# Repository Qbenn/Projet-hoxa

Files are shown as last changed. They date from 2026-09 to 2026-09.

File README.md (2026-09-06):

# Napęd wentylatora — projekt PKM

Projekt konstrukcyjny napędu wentylatora wykonany w ramach przedmiotu
Podstawy Konstrukcji Maszyn (PKM).

## Zawartość

| Plik | Opis |
|---|---|
| `design-calculations.pdf` | Dokumentacja obliczeniowa projektu |
| `assembly-drawing.pdf` | Rysunek złożeniowy |
| `driven-wheel-drawing.pdf` | Koło bierne (rysunek wykonawczy) |
| `shaft-drawing.pdf` | Wał (rysunek wykonawczy) |
| `fan-assembly.stl` | Model 3D złożenia (STL) |

## Technologie

- Modelowanie 3D / CAD
- Rysunek techniczny
- Obliczenia wytrzymałościowe (wał, łożyska, połączenia)

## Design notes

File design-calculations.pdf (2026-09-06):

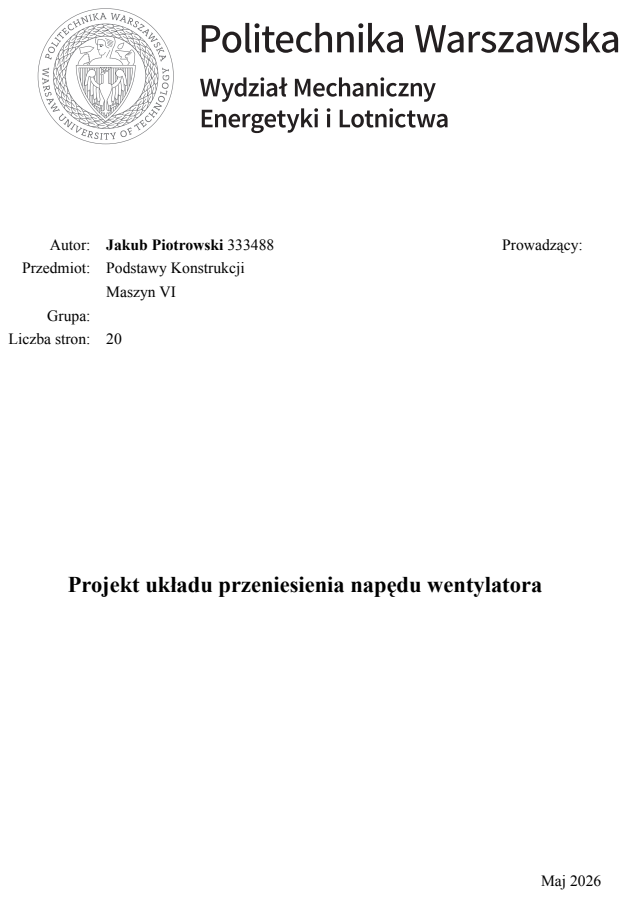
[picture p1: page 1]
Maszyn VI; Grupa:; Liczba stron: 20; Prowadzący:; Maj 2026

Autor: Jakub Piotrowski 333488
Przedmiot: Podstawy Konstrukcji

Projekt układu przeniesienia napędu wentylatora

## Spis treści

1 Wstęp | 1
1.1 Rysunek poglądowy i wymiary gabarytowe | | 1
1.2 Dane wyjściowe projektu | | 2
1.3 Zastosowane materiały | | 3
2 Dobór silnika elektrycznego | 4
3 Obliczenia przekładni pasowej | 4
4 Obliczenia wytrzymałościowe wału napędowego | 7
4.1 Rozplanowanie umieszczenia elementów na wale | | 7
4.2 Statyka wału | | 8
4.3 Rozkład obciążeń wewnętrznych | | 10
4.4 Analiza wytrzymałości doraźnej wału | | 11
4.5 Analiza ugięcia i obrotów krytycznych wału | | 12
4.6 Analiza wytrzymałości zmęczeniowej wału | | 12
4.7 Dobór wpustów | | 14
5 Dobór łożysk | 14
5.1 Wybrany model łożyska | | 14
5.2 Obliczenia sprawdzające nośność łożyska | | 15
5.3 Oprawy łożyskowe | | 16
6 Statyka ramy | 16
6.1 Konstrukcja ramy | | 16
6.2 Wstępna analiza MES ramy | | 17
7 System naciągu pasa | 18

## Spis rysunków

1 | Rysunek poglądowy układu napędowego wentylatora | | 1
2 | Widok ogólny układu napędowego | | 2
3 | Wymiary całego systemu | | 2
4 | Rozplanowanie umieszczenia elementów na wale | | 8
5 | Wał napędowy przed i po uwolnieniu od więzów | | 8
6 | Rozkład sił tnących i siły normalnej na wale | | 10
7 | Rozkład momentów gnących i skręcającego na wale | | 10
8 | Rozkład momentu zastępczego i wypadkowego momentu gnącego | | 11

9 | Porównanie średnicy teoretycznej i rzeczywistej wału napędowego | | 11
10 | Miejsca analizowane pod kątem wytrzymałości zmęczeniowej | | 12
11 | Izometryczny widok konstrukcji ramy | | 17
12 | Ugięcie ramy w kierunku Y (z odwzorowaniem kształtu ugięcia) | | 18
13 | System naciągu pasa SIT S.p.A. TC112 | | 19

## 1 Wstęp

Celem projektu jest zaprojektowanie układu przenoszenia napędu służącego do zasilania wentylatora. Urządzenie składa się z silnika elektrycznego, przekładni pasowej, systemu naciągu pasa, obudowanych łożysk i ramy.

### 1.1 Rysunek poglądowy i wymiary gabarytowe

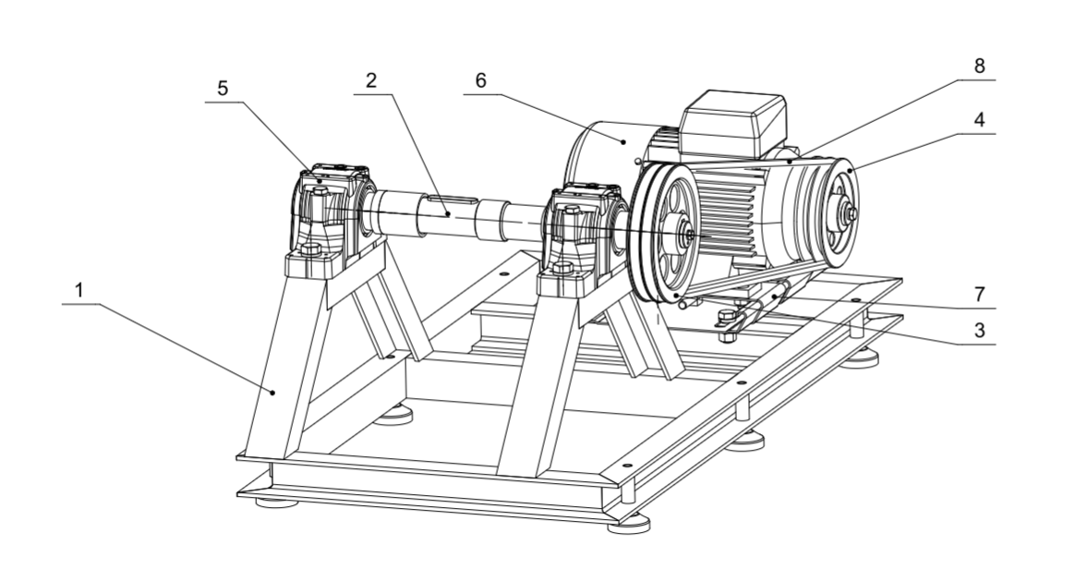
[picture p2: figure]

Rysunek 1: Rysunek poglądowy układu napędowego wentylatora

Głównymi elementami układu są:

1. rama,
2. wał napędowy,
3. koło bierne,
4. koło czynne,
5. łożyska w oprawie,
6. silnik elektryczny,
7. układ naciągu pasa,
8. pas klinowy.

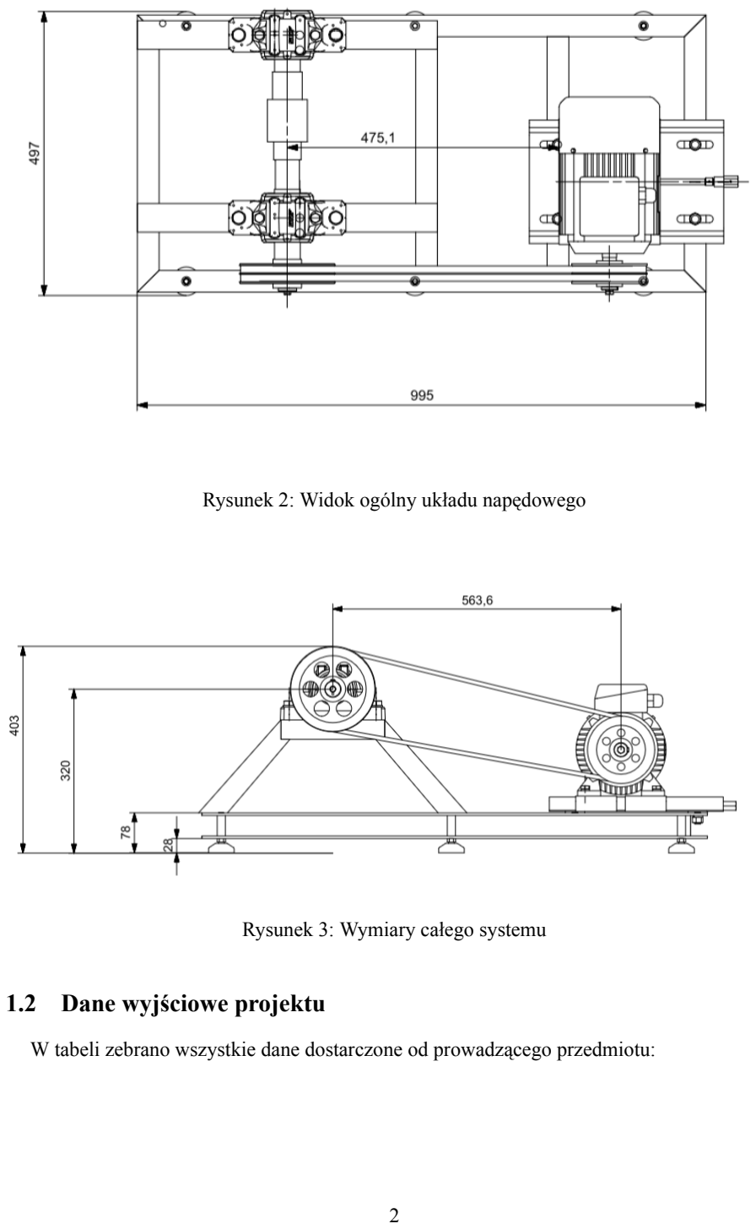
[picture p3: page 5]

Rysunek 2: Widok ogólny układu napędowego

Rysunek 3: Wymiary całego systemu

### 1.2 Dane wyjściowe projektu

W tabeli zebrano wszystkie dane dostarczone od prowadzącego przedmiotu:

OZNACZENIE WARTOŚĆ JEDNOSTKA
MOC UŻYTKOWA | P | 1,15 | kW
PRĘDKOŚĆ OBROTOWA | n | 1100 | obr/min
TRWAŁOŚĆ ŁOŻYSK | L10h | 125000 | h
SIŁA WZDŁUŻNA | FW | 310 | N
CIĘŻAR WENTYLATORA | FQ | 135 | N
WYMIAR GEOMETRYCZNY 1 | a | 515 | mm
WYMIAR GEOMETRYCZNY 2 | b | 322 | mm
WYMIAR GEOMETRYCZNY 3 | c | 320 | mm

Tabela 1: Parametry wejściowe

### 1.3 Zastosowane materiały

Zdecydowano, aby elementy urządzenia nieunormowane wykonać z następujących materiałów:

MATERIAŁ | PARAMETR | WARTOŚĆ | NORMA | ZASTOSOWANIE
S235JR | Re Rm | 235 MPa 410 MPa | PN-EN 10025:2002 | rama, tulejki gwintowane, płytki wyrównujące
C35 | Re Rm Zgo | 300 MPa 520 MPa 238,5 MPa | PN-EN 10083-2 | wał napędowy, tulejki dystan-sujące
C45 | Re Rm | 305 MPa 580 MPa | PN-EN 10083-2 | wpusty
PN-GJL 200 | Rm HB | 155 MPa 150 | PN-EN 1561:2000 | koła przekładni pasowej

Tabela 2: Właściwości materiałów użytych w projekcie

Stal S235JR wybrano do wykonania ramy ze względu na jej łatwą obróbkę i dobrą spawalność. Stale C35 i C45 wybrano ze względu na ich dobre właściwości wytrzymałościowe, możliwość umacniania cieplnego oraz łatwą obróbkę skrawaniem. Zdecydowano, aby koła przekładni wykonać w technologii odlewania.

## 2 Dobór silnika elektrycznego

Moc niezbędna:

Prozp =

Puzyt
ηo

=

P
ηpp ·ηb ·ηb

Na podstawie danych przedstawionych w [1] przyjęto następujące wartości współczynników:

WIELKOŚĆ | OZNACZENIE WARTOŚĆ LICZBOWA
SPRAWNOŚĆ PRZEKŁADNI PASOWEJ | ηpp | 0,93
SPRAWNOŚĆ PARY ŁOŻYSK KULKOWYCH | ηb | 0,99

Tabela 3: Wartości sprawności w układzie przeniesienia napędu

Stąd minimalna moc silnika elektrycznego wynosi:

Prozp =

Puzyt
ηo

=

1,15
0,93 · 0,99 · 0,99

≈ 1,26 kW

Na podstawie obliczeń dobrano trójfazowy silnik indukcyjny firmy Celma Indukta, model SH90L-4, o mocy 1,5 kW i prędkości 1410 obr/min. Jego parametry przedstawiono w tabeli:

OZNACZENIE WARTOŚĆ JEDNOSTKA

MOC ZNAMIONOWA | Ps | 1,5 | kW
PRĘDKOŚĆ OBROTOWA | ns | 1410 | obr/min

Tabela 4: Wybrane parametry silnika

Teoretyczne przełożenie układu przenoszenia napędu:

ut =

ns
n
| =
| 1410
| 1100

≈ 1,28

Moment na wale silnika wynosi:

T1 =

Prozp
ns
- 9550 =
| 1,26
| 1410 | · 9550 = 8,534 Nm

## 3 Obliczenia przekładni pasowej

Pierwszym krokiem jest wybranie typu paska. W tym celu należy obliczyć moment obliczeniowy na wale silnika:
| T10 = kt

·T1

Współczynnik kt uwzględnia trwałość pasa klinowego. Dla lekkich warunków pracy, silnika trójfazowego i pracy do 16 godzin na dobę przyjęto kt = 1,2:

T1o = 1,2 · 8,534 = 10,24 Nm < 30 Nm

Przyjęty typ paska to HA. Średnicę skuteczną koła czynnego wybrano równą rozmiarowi

odpowiadającemu jak najlepszej wartości przenoszenia napędu: D1s = 125 mm. Prędkość pasa wynosi:
ϑ =

D1s

- n1 · π
60 · 10³

= 9,223

m
s

< 25 m
s
Zatem warunek prędkości pasa jest spełniony. Średnicę skuteczną koła biernego przyjęto jako pierwszy rozmiar mniejszy lub równy średnicy teoretycznej. Średnicę teoretyczną wyznaczono

z:

D2t = D1s

·it = 125 · 1,28 ≈ 160 mm

D2s = 160 mm

Rzeczywiste przełożenie przekładni obliczono z zależności:

i =

D2s

D1s

·(1−ε)

Współczynnik ε opisuje poślizg sprężysty pasa. Jego wartość przyjęto równą ε = 0,015.

Podstawiając:

i =

160
125 ·(1−0,015)

≈ 1,299

# |it −i|

i

=

|1,28−1,299|
1,28

≈ 1,48% < 4%

Zatem warunek jest spełniony. Odległość osi dobrano z warunku postawionego w założeniach projektowych: az = 570 mm. Jest ona większa niż odległość zalecana, wyznaczona z zależności, gdzie ka to współczynnik odległości osi:

at = ka ·D2s = 1,2 · 160 = 192 mm

Obliczeniową długość pasa obliczono ze wzoru:

Lp = 2az +0,5π ·(D2s +D1s) +0,25 ·

(D2s −D1s)

2

az

= 1588,24 mm

Rzeczywista wartość na podstawie tabeli w literaturze:

Lp = 1600 mm

Ostateczna odległość między osiami silnika i wentylatora:

a = az +0,5 ·(Lp −L

′
p

) = 575,89 mm

Liczba obiegów pasa i kąt opasania koła czynnego wynoszą:

ν =

10³

·ϑ

Lp

=

1000 · 9,22
1600

= 5,77 < 15 = νdop

α = 180◦ −57◦
·

D2s −D1s
a

= 180◦ −57◦
·

160−125
570 = 176◦ > 110◦

Oba warunki z literatury są spełnione. Moc przenoszona przez jeden pas:

Pobl = P0 · kl

- kα

gdzie P0 = 2 kW to nominalna moc przenoszona przez jeden pas (odczytana z tablic dla D1s = 125 mm, ϑ ≈ 10 m/s), kl = 0,99 to współczynnik uwzględniający długość pasa, zaś kα = 0,99

to współczynnik uwzględniający kąt opasania koła czynnego. Wartości odczytano z tablic w literaturze:
Pobl = 2 · 0,99 · 0,99 = 1,96 kW

Obliczeniowa liczba pasów wynosi:

zobl =

P1 · kT

Pobl

=

1,8 · 1,2
1,96

≈ 1,10

Przyjęto liczbę pasów z = 2. Obciążenia występujące w przekładni obliczono z zależności:

Ft =

2 · 10³
·T1o

D1s

=

2000 · 10,24
125

≈ 163,84 N

F0 =

Ft
2 ·Ψ

=

163,84
2 · 0,55

≈ 148,94 N

F = 2 ·F0 ·sin(α

2

)

= 2 · 148,94 ·sin(
176◦

2

)
= 298,1 N

gdzie Ψ = 0,55 to współczynnik napędu. Dla przekładni z okresową kontrolą napięcia pasa

maksymalna siła obciążająca wał wynosi:

Fmax = 1,3 ·F = 1,3 · 298,1 = 387,65 N

W tabeli zestawiono wszystkie obliczone lub przyjęte wielkości użyte w tym rozdziale.

| OZNACZENIE | WARTOŚĆ | JEDNOSTKA
WSPÓŁCZYNNIK TRWAŁOŚCI PASA | kT | 1,2 | -
MOMENT OBLICZENIOWY | T1o | 10,24 | Nm
ŚREDNICA KOŁA CZYNNEGO | D1s | 125 | mm
PRĘDKOŚĆ PASA | ϑ | 9,223 | m/s
MAKSYMALNA ŚREDNICA KOŁA BIERNEGO | D2max | 160 | mm
PRZYJĘTA ŚREDNICA KOŁA BIERNEGO | D2 | 160 | mm
WSPÓŁCZYNNIK POŚLIZGU | ε | 0,015 | -
RZECZYWISTE PRZEŁOŻENIE | urz | 1,299 | -
WARUNEK PRZEŁOŻEŃ | - | 1,48% | -
WSPÓŁCZYNNIK ODLEGŁOŚCI MIĘDZY KOŁAMI | ka | 1,2 | -
ZALECANA ODLEGŁOŚĆ OSI | at | 192 | mm
OBLICZENIOWA DŁUGOŚĆ PASA | L

′
| p | 1588,24 | mm
PRZYJĘTA ODLEGŁOŚĆ MIĘDZY OSIAMI KÓŁ | az | 570 | mm
RZECZYWISTA DŁUGOŚĆ PASA | Lp | 1600 | mm
OSTATECZNA ODLEGŁOŚĆ MIĘDZY OSIAMI KÓŁ | a | 575,89 | mm
LICZBA OBIEGÓW PASA | ν | 5,77 | 1/s
KĄT OPASANIA KOŁA CZYNNEGO | α | 176 | ◦
WSPÓŁCZYNNIK DŁUGOŚCI PASA | kl | 0,99 | -
WSPÓŁCZYNNIK KĄTA OPASANIA | kα | 0,99 | -
MOC NOMINALNA PRZENOSZONA PRZEZ PAS | P0 | 2 | kW
MOC PRZENOSZONA PRZEZ JEDEN PAS | Pobl | 1,96 | kW
OBLICZENIOWA LICZBA PASÓW | zobl | 1,1 | -
WYBRANA LICZBA PASÓW | z | 2 | -
SIŁA OBWODOWA | Ft | 163,84 | N
WSPÓŁCZYNNIK NAPĘDU | Ψ | 0,55 | -
NAPIĘCIE WSTĘPNE PASA | F0 | 148,94 | N
SIŁA OBCIĄŻAJĄCA WAŁ | F | 298,1 | N
SIŁA MAKSYMALNA DLA PRZEKŁADNI Z KONTROLĄ PASA | Fmax | 387,65 | N

Tabela 5: Zestawienie wielkości użytych do obliczeń przekładni

## 4 Obliczenia wytrzymałościowe wału napędowego

### 4.1 Rozplanowanie umieszczenia elementów na wale

Przed rozpoczęciem obliczeń należy rozplanować rozkład elementów układu na wale napędowym. Uproszczony rysunek przedstawiający rozmieszczenie najważniejszych elementów zamieszczono poniżej.

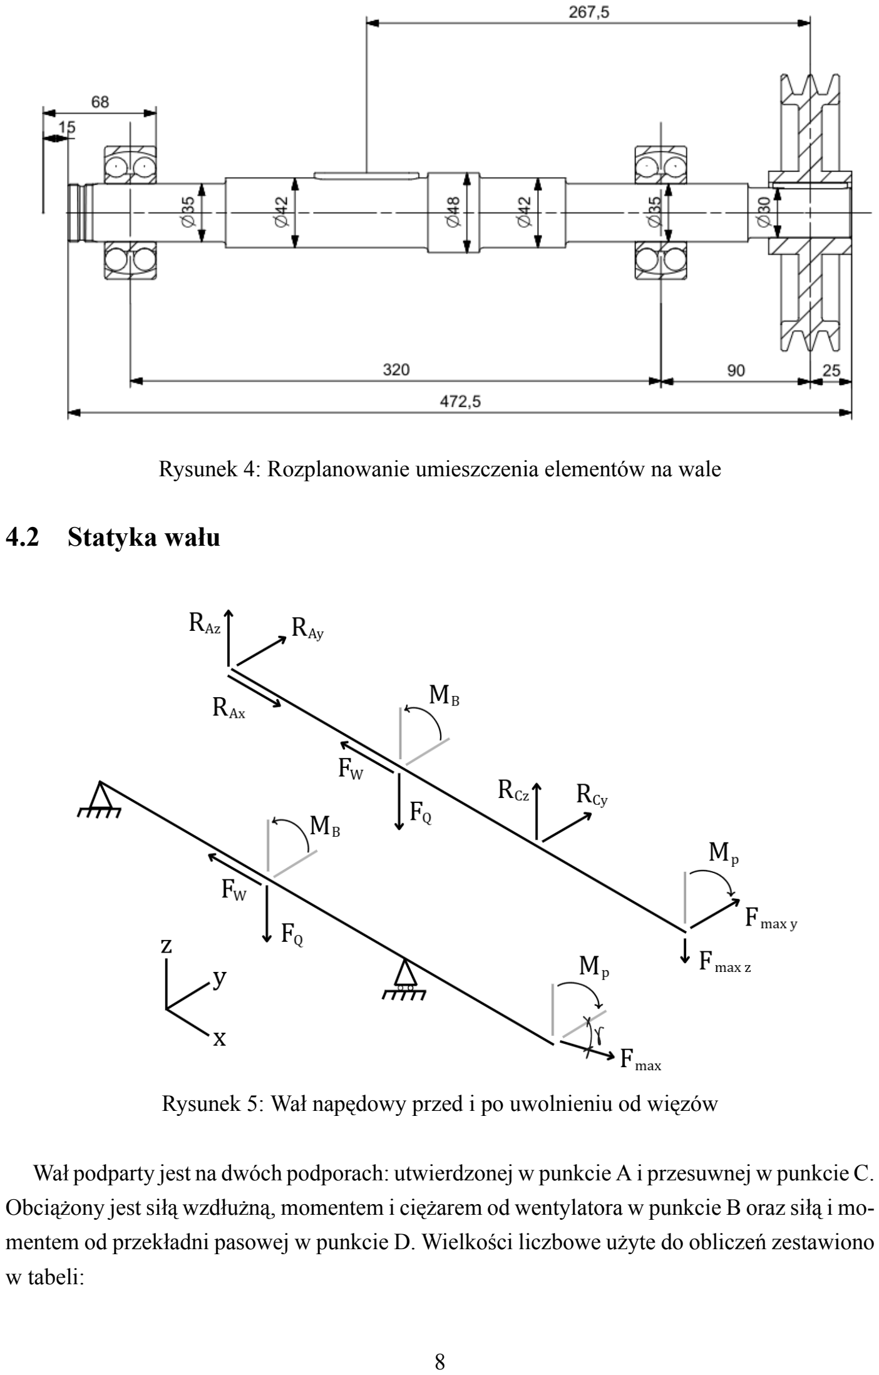
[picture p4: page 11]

Rysunek 4: Rozplanowanie umieszczenia elementów na wale

### 4.2 Statyka wału

Rysunek 5: Wał napędowy przed i po uwolnieniu od więzów

Wał podparty jest na dwóch podporach: utwierdzonej w punkcie A i przesuwnej w punkcie C. Obciążony jest siłą wzdłużną, momentem i ciężarem od wentylatora w punkcie B oraz siłą i momentem od przekładni pasowej w punkcie D. Wielkości liczbowe użyte do obliczeń zestawiono w tabeli:

| OZNACZENIE | WARTOŚĆ | JEDNOSTKA
SIŁA WZDŁUŻNA | FW | 310 | N
CIĘŻAR WENTYLATORA | FQ | 135 | N
MAKSYMALNA SIŁA OBCIĄŻAJĄCA WAŁ OD PRZEKŁADNI | Fmax | 387,65 | N
KĄT POMIĘDZY PŁASZCZYZNĄ XY I SIŁĄ Fmax | γ | 0,296 | rad
SKŁADOWA NA KIERUNEK y SIŁY OBCIĄŻAJĄCEJ WAŁ | Fmax,y | 370,7 | N
SKŁADOWA NA KIERUNEK z SIŁY OBCIĄŻAJĄCEJ WAŁ | Fmax,z | 113,3 | N
MOMENT OD PRZEKŁADNI | Mp | 9,98 | Nm
ODLEGŁOŚĆ MIĘDZY ŁOŻYSKIEM A A PUNKTEM PRZYŁOŻENIA SIŁ OD WENTYLATORA | lAB | 142.5 | mm
ODLEGŁOŚĆ MIĘDZY ŁOŻYSKIEM A A ŁOŻYSKIEM C | lAC | 320 | mm
ODLEGŁOŚĆ MIĘDZY ŁOŻYSKIEM A A PUNKTEM PRZYŁOŻENIA SIŁ OD KOŁA PASOWEGO | lAD | 410 | mm

Tabela 6: Wartości obciążeń i wymiarów użyte do obliczeń statyki

Poniżej przedstawiono równania równowagi statycznej dla opisanego układu:

∑Fx = RAx −FW = 0

∑Fy = RAy +RCy +Fmax,y = 0

∑Fz = RAz +RCz −Fmax,z −FQ = 0

∑MDx = MB − Mp = 0

∑MDy = RAz ·lAD −FQ ·lBD +RCz ·lCD = 0

∑MDz = −RAy ·lAD −RCy ·lCD = 0

Po rozwiązaniu równań otrzymano:

Wielkość Wartość Jednostka
RAx | 310 | N
RAy | 104,26 | N
RAz | 43 | N
RCy | −474,9 | N
RCz | 205,3 | N
FQ | 135 | N
MB | 9,98 | Nm

Tabela 7: Reakcje wyznaczone z równań równowagi statycznej

Na potrzeby rozwiązania układu założono, że reakcja wzdłużna odbierana jest przez łożysko A.

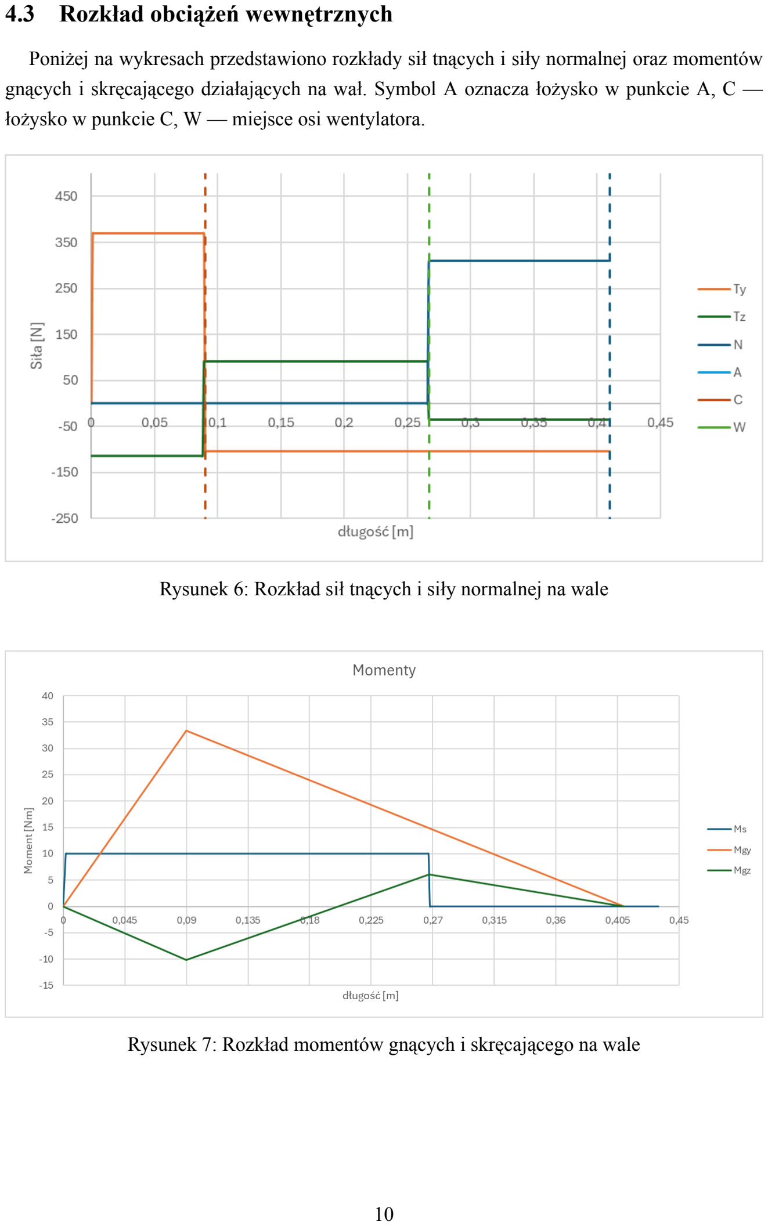
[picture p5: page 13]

### 4.3 Rozkład obciążeń wewnętrznych

Poniżej na wykresach przedstawiono rozkłady sił tnących i siły normalnej oraz momentów gnących i skręcającego działających na wał. Symbol A oznacza łożysko w punkcie A, C — łożysko w punkcie C, W — miejsce osi wentylatora.

Rysunek 6: Rozkład sił tnących i siły normalnej na wale

Rysunek 7: Rozkład momentów gnących i skręcającego na wale

### 4.4 Analiza wytrzymałości doraźnej wału

Aby wyznaczyć minimalny promień z warunku wytrzymałości doraźnej, posłużono się wzorem z [1]:

r0 =

1
2

·
3

√
Mzast · 1000 · n
Zgo · 0,1

gdzie n = 1,5 to przyjęty współczynnik bezpieczeństwa, Zgo to granica wytrzymałości materiału na zginanie obustronne, która dla stali C35 wynosi 238,5 MPa. Moment zastępczy wyznaczono ze wzoru:

Mzast =

√
M²

gz + M²

gy + (α · Ms)
2

Wartość współczynnika α przyjęto zakładając, że kierunek obrotu wału się nie zmienia:
α ≈

√
3
4

. Poniżej na wykresach przedstawiono rozkład momentu zastępczego, promienia minimalnego i przyjętych promieni wału napędowego. Przyjęte promienie zostały dobrane z wystarczającym zapasem, zapewniającym odporność wału na zniszczenie doraźne.

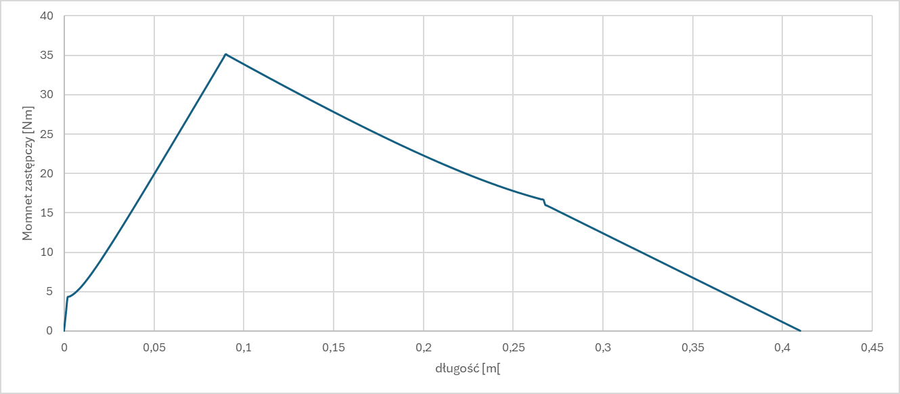
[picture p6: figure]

Rysunek 8: Rozkład momentu zastępczego i wypadkowego momentu gnącego

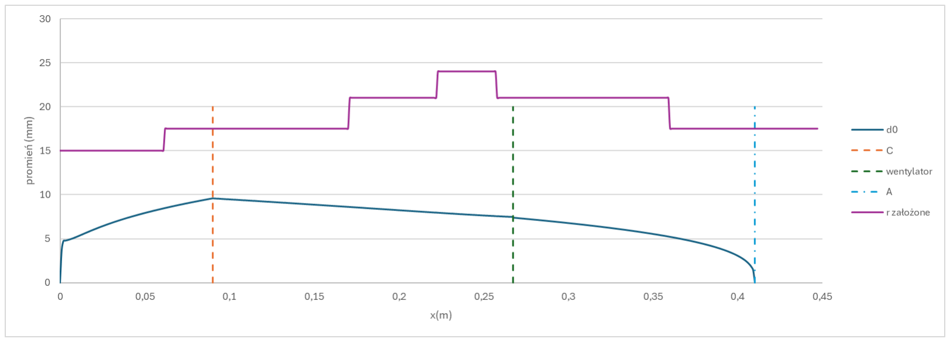
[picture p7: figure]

Rysunek 9: Porównanie średnicy teoretycznej i rzeczywistej wału napędowego

Rzeczywiste średnice są zdecydowanie większe niż wyniki teoretyczne. Wynika to z faktu, że najbardziej krytycznym warunkiem wytrzymałościowym jest ugięcie wału oraz wymagana trwałość godzinowa łożysk, a nie wytrzymałość doraźna.

### 4.5 Analiza ugięcia i obrotów krytycznych wału

Do wyznaczenia ugięcia wału przyjęto model uproszczony ze stałą średnicą równą średnicy minimalnej. Ugięcie wału obliczono ze wzoru:

fc =

P· a

2

3EJy

(l +a)

gdzie P = 387,67 N to siła od przekładni, a = 97,5 mm to odległość przyłożenia siły od łożyska C, l = 320 mm to odległość między łożyskami, E = 2,1·10⁵ MPa to moduł Younga dla stali, a Jy dla najmniejszej średnicy wału (d = 35 mm) wynosi Jy = 73661,4 mm⁴
. Podstawiając:

fc =

387,65 · 97,5

2
·(320+97,5)
3 · 2,1 · 10⁵
- 73661,4

= 0,0458 mm < l · 10−4 = 0,064 mm

Prędkość krytyczna dla wyznaczonego ugięcia:

nkr =

√ g

fc

=

√
9,81
0,0458 · 10−3

≈ 462,5

rad
s

0,85 · nkr = 0,85 · 462,5 ·

60
2π

= 3754 obr
min > 1100

obr
min
Warunki ugięcia i prędkości krytycznej są spełnione.

### 4.6 Analiza wytrzymałości zmęczeniowej wału

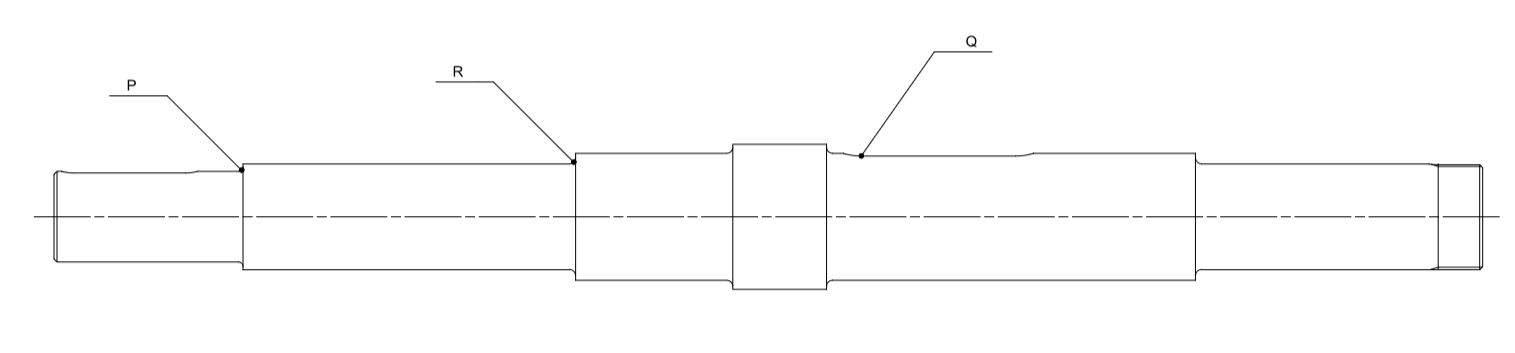
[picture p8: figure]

Rysunek 10: Miejsca analizowane pod kątem wytrzymałości zmęczeniowej

Do zbadania wytrzymałości zmęczeniowej wału wybrano trzy przekroje, w których przewiduje się największe zagrożenie uszkodzeniem zmęczeniowym: odsadzenie w punkcie P, odsadzenie w punkcie R oraz rowek wpustowy pod piastę wentylatora w punkcie Q.

Rzeczywisty współczynnik bezpieczeństwa dla obciążeń złożonych obliczono z zależności:

δ = √

## δσ · δτ

δ
2

σ +δ
2
τ

gdzie δσ to współczynnik bezpieczeństwa na zginanie, a δτ to współczynnik bezpieczeństwa

na skręcanie, obliczone ze wzorów:
δσ =

Zgo · ε

## σa · β

δτ =

Zso · ε

## τa · β +ψ · τm

Symbole: Zgo, Zso — granice wytrzymałości zmęczeniowej materiału; ε — współczynnik wielkości; ψ — współczynnik podatności na asymetrię cyklu; β — wypadkowy współczynnik działania karbu; σa, τa — amplitudy naprężeń normalnych i stycznych. Dla stałego kierunku obrotów wału przyjęto τa = τm. Wypadkowy współczynnik działania karbu obliczono ze wzoru

podanego w [4]:

## β = βk +βp −1 = 1+ (αk −1)ηk +βp −1

Dla obliczenia współczynnika bezpieczeństwa w rowku wpustowym (punkt Q) użyto wartości współczynników działania karbu podanych w [1]. Wyznaczone wartości oraz końcowe wyniki zestawiono w tabeli:

Parametr | P | Q | R | Jednostka
d | 30 | 42 | 35 | mm
Wg | 2651 | 7273,57 | 4209,24 | mm³
Mg | 14,94 | 20,7 | 28,178 | Nm
Ms | 10 | 10 | 10 | Nm
σa | 5,639 | 2,846 | 6,694 | MPa
τa | 1,89 | 0,687 | 1,19 | MPa
Zgo | 238,5 | 238,5 | 238,5 | MPa
Zso | 141 | 141 | 141 | MPa
ε | 0,87 | 0,83 | 0,85 | -
βkσ | 1,95 | 1,75 | 1,85 | -
βkτ | 1,50 | 1,50 | 1,40 | -
βpσ | 1,08 | 1,08 | 1,00 | -
βpτ | 1,08 | 1,08 | 1,00 | -
βσ | 2,03 | 1,83 | 1,85 | -
βτ | 1,58 | 1,58 | 1,40 | -
ψτ | 0,05 | 0,05 | 0,05 | -
δσ | 18,13 | 38,00 | 16,37 | -
δτ | 39,82 | 107,5 | 68,29 | -
δ | 16,50 | 35,83 | 15,92 | -

Tabela 8: Wyniki obliczeń współczynników bezpieczeństwa zmęczeniowego (wg Kurmaz, Tabl. 8.6.1 i 8.6.2, Rys. 8.6.5)

W wszystkich analizowanych przekrojach współczynniki bezpieczeństwa zmęczeniowego są co najmniej ośmiokrotnie wyższe od przyjętego współczynnika bezpieczeństwa. Warunek wytrzymałości zmęczeniowej jest spełniony.

### 4.7 Dobór wpustów

Zdecydowano, aby wpust pod piastą wentylatora mocowany był na wcisk, a wpust pod piastą koła biernego połączeniem gwintowym. Dopuszczalne naciski powierzchniowe wynoszą odpowiednio: pdop = 30 MPa dla wpustu pod piastą wentylatora i pdop = 60 MPa dla wpustu pod piastą koła. Długość wpustu wyznaczono z warunku nacisków dopuszczalnych:

l ≥

2ktM · 1000
pdop · d ·(h−t1)

Dla wpustu pod piastą koła biernego: h = 7 mm, d = 30 mm, t1 = 4 mm, b = 8 mm:

l ≥

2 · 1,2 · 9,98 · 1000
60 · 30 ·(7−4)

≥ 4,76 mm

Dla wpustu pod piastą wentylatora: h = 8 mm, d = 42 mm, t1 = 5 mm, b = 12 mm:

l ≥

2 · 1,2 · 9,98 · 1000
30 · 42 ·(8−5)

≥ 6,34 mm

Przyjęto wpusty o jednakowej długości, wynoszącej 45 mm (minimalna dla wpustu o szerokości 8 mm). Dobrano wpust C 8×7×45 do koła pasowego oraz wpust A 12×8×63 dla wentylatora zgodnie z normą PN-70/M-85005. Wpust pod koło czynne jest zintegrowany z wałem silnika.

## 5 Dobór łożysk

### 5.1 Wybrany model łożyska

Zastosowano łożyska kulkowe wahliwe, eliminujące wpływ błędów współosiowości wynikających z ugięcia wału lub niedokładności montażowych. Dobrano łożyska 2307 ETN9 z katalogu firmy SKF [5]. Ich parametry przedstawiono poniżej:

Parametr | Wartość Jednostka
Średnica otworu d | 35 | mm
Średnica zewnętrzna D | 80 | mm
Szerokość b | 31 | mm
Nośność dynamiczna C | 39,7 | kN
Nośność statyczna C0 | 11,2 | kN
Prędkość graniczna ngr | 12000 | obr/min
Prędkość nominalna nnom | 16000 | obr/min
e | 0,46 | -
Y0 | 1,4 | -
Y1 | 1,4 | -
Y2 | 2,1 | -
Graniczne obciążenie zmęczeniowe Pu | 0,585 | kN

Tabela 9: Parametry dobranego łożyska 2307 ETN9

### 5.2 Obliczenia sprawdzające nośność łożyska

Prędkość graniczna łożyska znacznie przekracza prędkość obrotową układu. Trwałość godzinową łożyska obliczono zgodnie z metodyką przedstawioną w literaturze [5]:

L10ht =

10⁶

n · 60 (
C
P

)k

Sprawdzano łożysko obciążone reakcją wzdłużną — łożysko w punkcie A. Promieniowa składowa obciążenia:

Fp =

√
R

2
Ay +R

2
Az =

√
104,3

2 +43,02² = 112,78 N

Fw = RAx = 310 N

Fw
Fp

=

310
112,78

= 2,74 > e

Obciążenie zastępcze:

P = 0,65 ·Fp +Y2 ·Fw = 0,65 · 112,78+2,1 · 310 = 724,3 N

Teoretyczna trwałość godzinowa łożyska:

L10ht =

10⁶

1101 · 60 (
39700
724,3

)3
= 2 124 409 h

Już teoretyczna trwałość łożyska wielokrotnie przekracza wymagane 125 000 h.

### 5.3 Oprawy łożyskowe

Zastosowano oprawy łożyskowe SKF SNL 208-307 [6], dostosowane do łożysk o średnicy zewnętrznej D = 80 mm. W obu oprawach zastosowano pierścienie uszczelniające TSN 509A typu V-ring, dopuszczające nieosiowość wału i pierścienia uszczelniającego, łatwe w montażu. W oprawie od strony koła pasowego nie zastosowano pierścieni ustalających, tworząc podporę pływającą — umożliwia to kompensację odkształceń termicznych i błędów montażowych. Oprawa od strony wentylatora stanowi podporę ustalającą; zamknięto ją zaślepką SKF ASNH510 w celu uszczelnienia obudowy. Do blokowania łożyska i piasty wentylatora użyto nakrętki i podkładki łożyskowej KM 7 i MB 7.

## 6 Statyka ramy

### 6.1 Konstrukcja ramy

Ramę wykonano z dwuteowników ze stali S235JR, połączonych spawami pachwinowymi. Do prostokątnego obrysu dospawano belki poprzeczne, na których podparte są oprawy łożysk oraz podstawa silnika. Aby wypoziomować ramę, w sześciu punktach dospawano gwintowane tulejki, w które wkręcone są regulowane stopki Kipp K0742. Wyrównanie powierzchni pod układ napinania pasa zapewniono przez dospawanie płytek i wyfrezowanie ich do jednej płaszczyzny. Elementy układu przeniesienia napędu mocowane są na ramie połączeniami gwintowanymi z użyciem nakrętek samokontrujących.

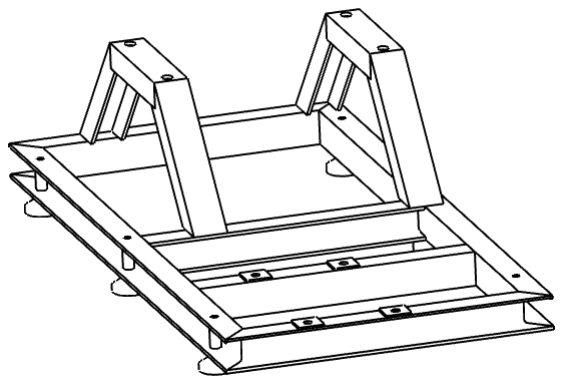
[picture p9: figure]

Rysunek 11: Izometryczny widok konstrukcji ramy

### 6.2 Wstępna analiza MES ramy

W celu zbadania ugięcia ramy pod wpływem obciążeń podczas pracy wykonano uproszczoną analizę MES. Silnik i oprawy łożysk zastąpiono ich uproszczoną geometrią. Model wykonano zgodnie ze wskazówkami z [7]. Ramę obciążono reakcjami odebranymi z łożysk. Poniżej przedstawiono mapę ugięcia ramy w kierunku Y:

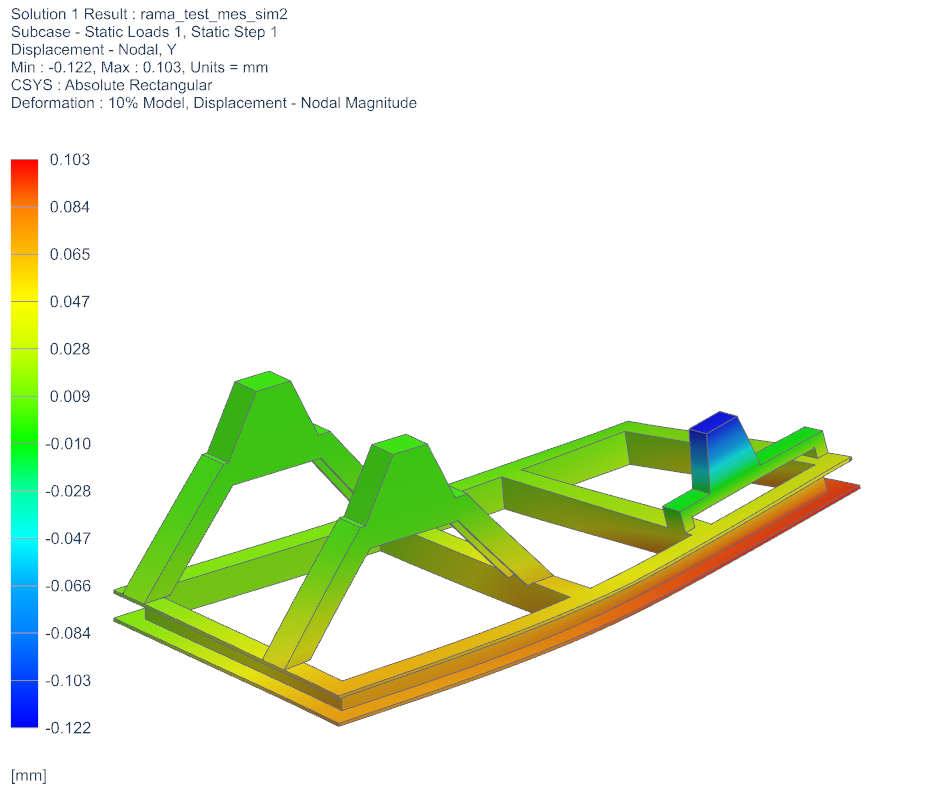
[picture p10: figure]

Rysunek 12: Ugięcie ramy w kierunku Y (z odwzorowaniem kształtu ugięcia)

Maksymalne ugięcie ramy wynosi 0,122 mm. Jest to wartość znikoma w porównaniu z możliwym zakresem kompensacji odkształceń przez układ napinania pasa. Sztywność ramy jest zatem wystarczająca.

## 7 System naciągu pasa

W projekcie zastosowano gotowy system napinania pasa firmy SIT S.p.A. o numerze katalogowym TC112. Rozwiązanie jest przystosowane do wybranego silnika o rozmiarze 90L. Naciąg reguluje się śrubą, co zapewnia szeroki zakres regulacji wynoszący 154 mm dla silnika 90L. Silnik porusza się na sankach, które przemieszczają się po prowadnicach.

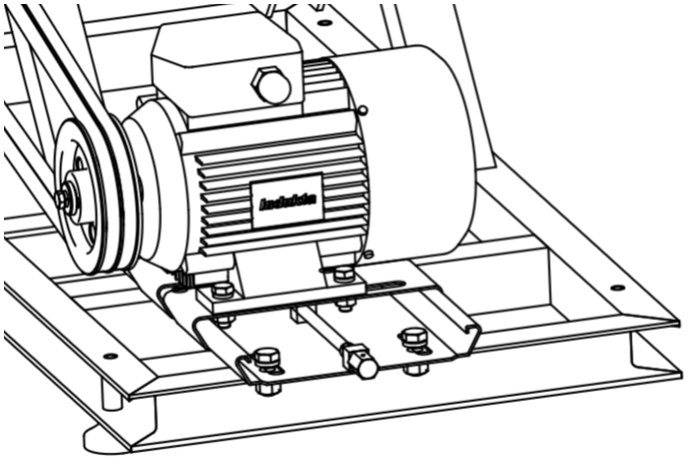
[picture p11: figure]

Rysunek 13: System naciągu pasa SIT S.p.A. TC112

## Literatura

[1] Oleg L. Kurmaz, Leonid W. Kurmaz. Projektowanie węzłów i części maszyn. Wydawnictwo Politechniki Świętokrzyskiej, 2007. ISBN: 978-83-88906-81-7.
[2] Zbigniew Dąbrowski. Wały maszynowe. Wydawnictwo Naukowe PWN, 1999.
[3] Eugeniusz Mazanek. Przykłady obliczeń z podstaw konstrukcji maszyn, tom I. Wydawnictwo Naukowe PWN, 2008. ISBN: 978-83-204-3418-7.
[4] Józef Szala, Stanisław Kocańda. Podstawy obliczeń zmęczeniowych. Wydawnictwo Naukowe PWN, 1991. ISBN: 83-01-05889-7.
[5] SKF. Łożyska toczne. PUB BU/P1 10000 PL, wrzesień 2014.
[6] SKF. SNL plummer block housings. Luty 2015.
[7] dr Jacek Gadomski. PKM 6 — opracowanie. 2021.

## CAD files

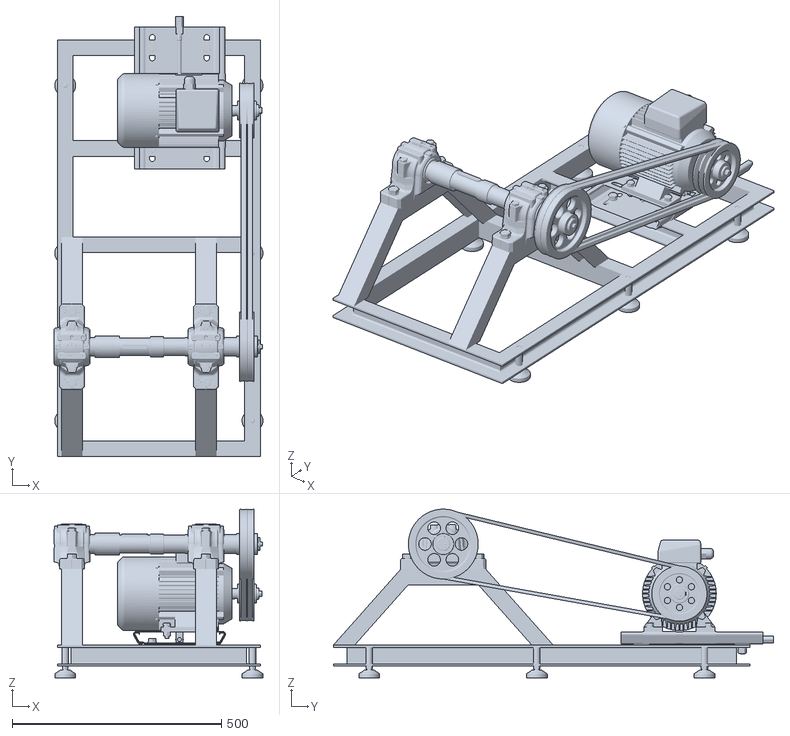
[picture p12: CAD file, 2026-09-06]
fan-assembly.stl
498.8 x 1051.0 x 402.7

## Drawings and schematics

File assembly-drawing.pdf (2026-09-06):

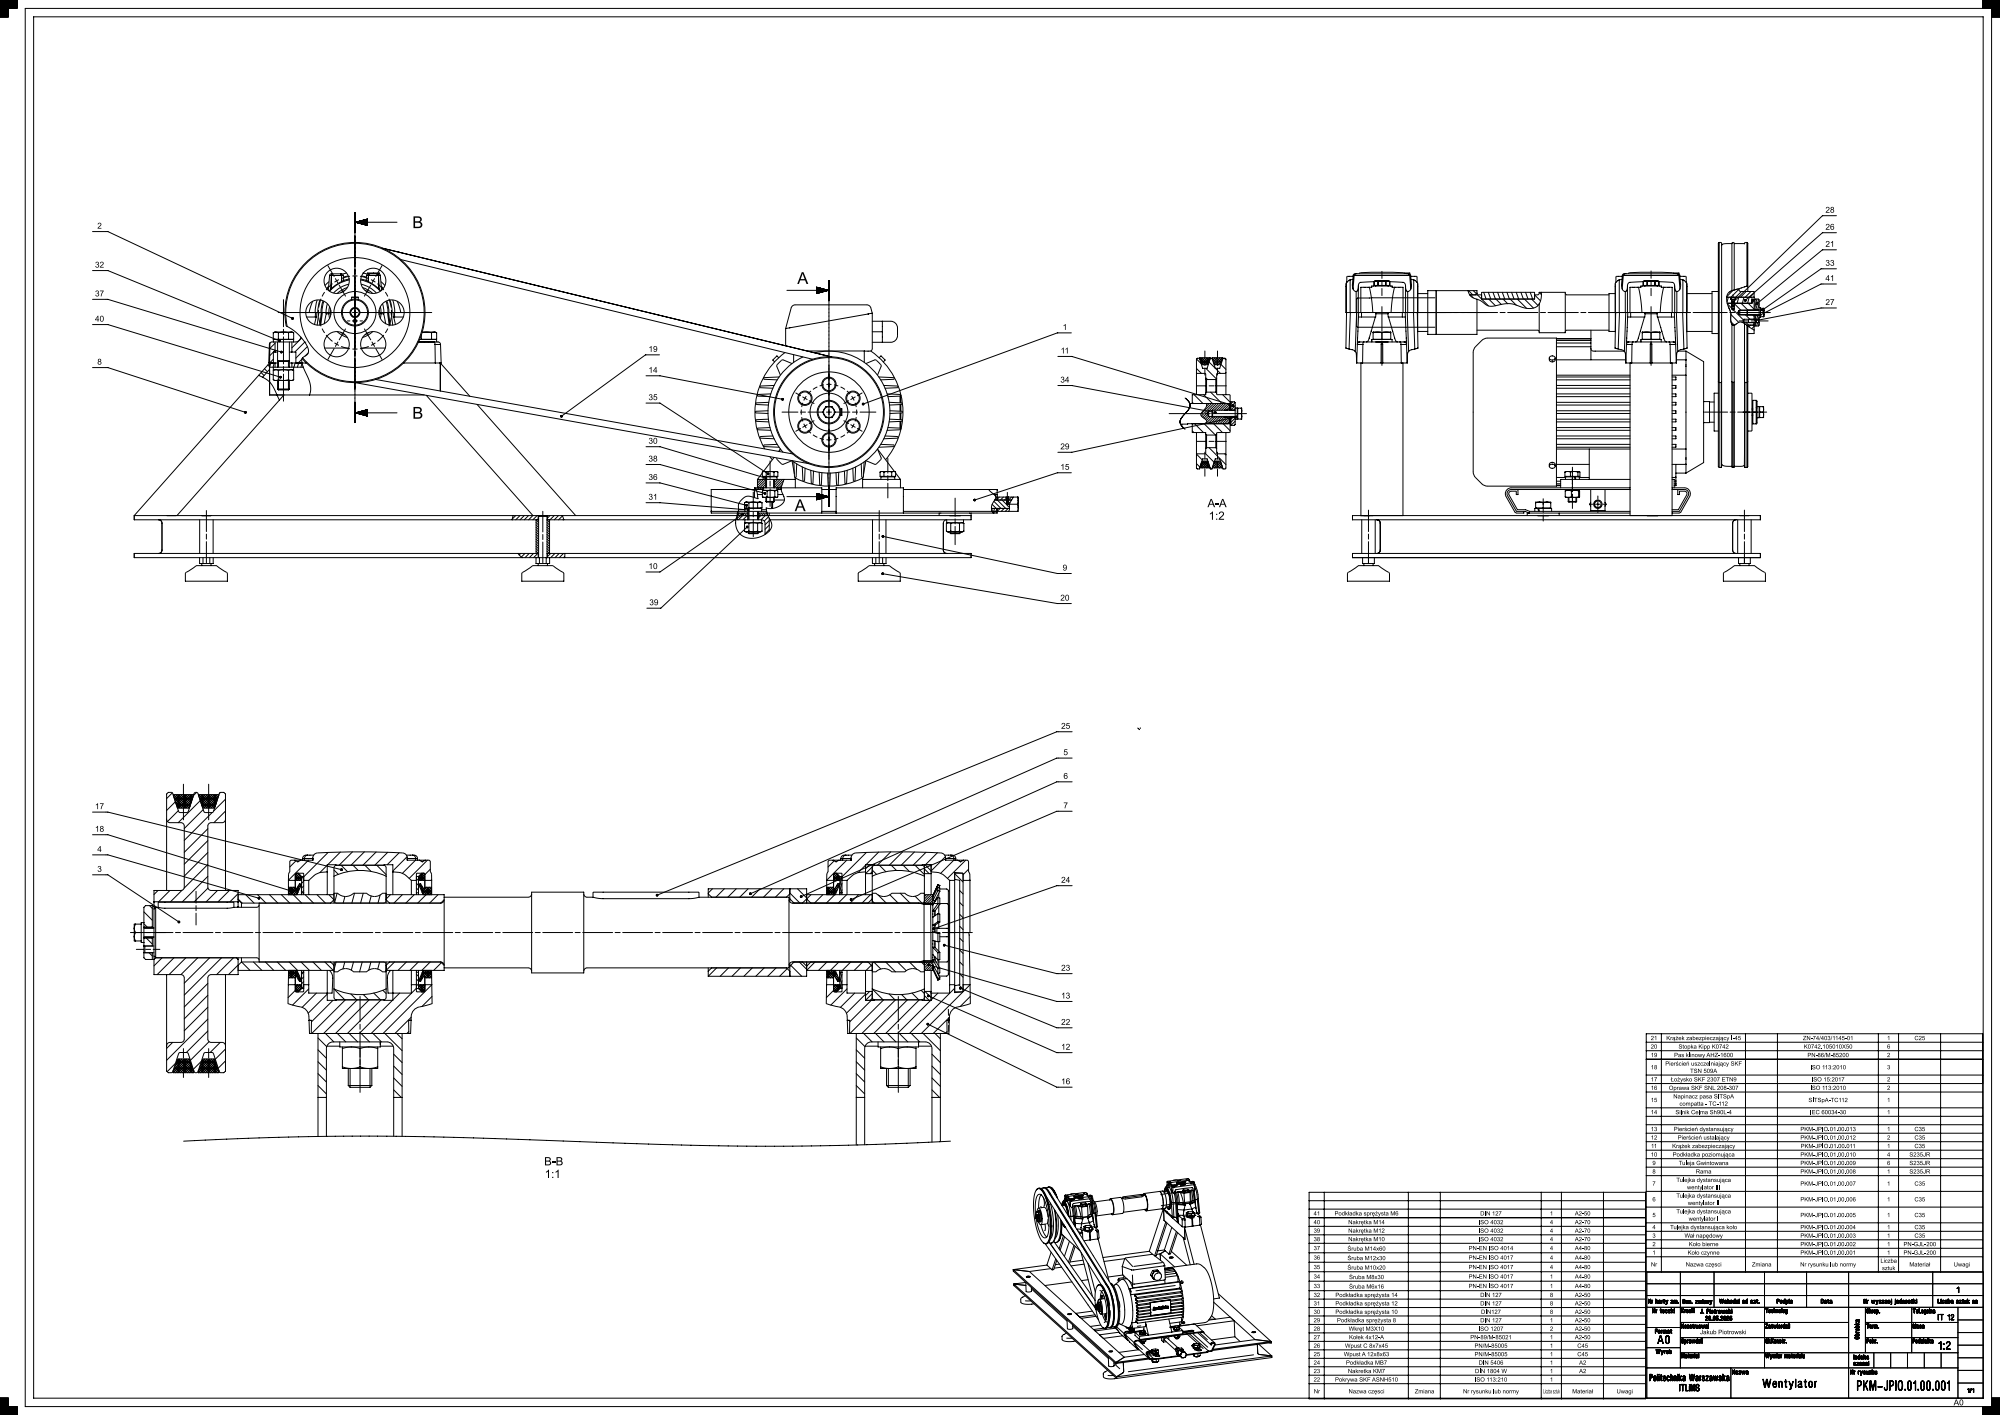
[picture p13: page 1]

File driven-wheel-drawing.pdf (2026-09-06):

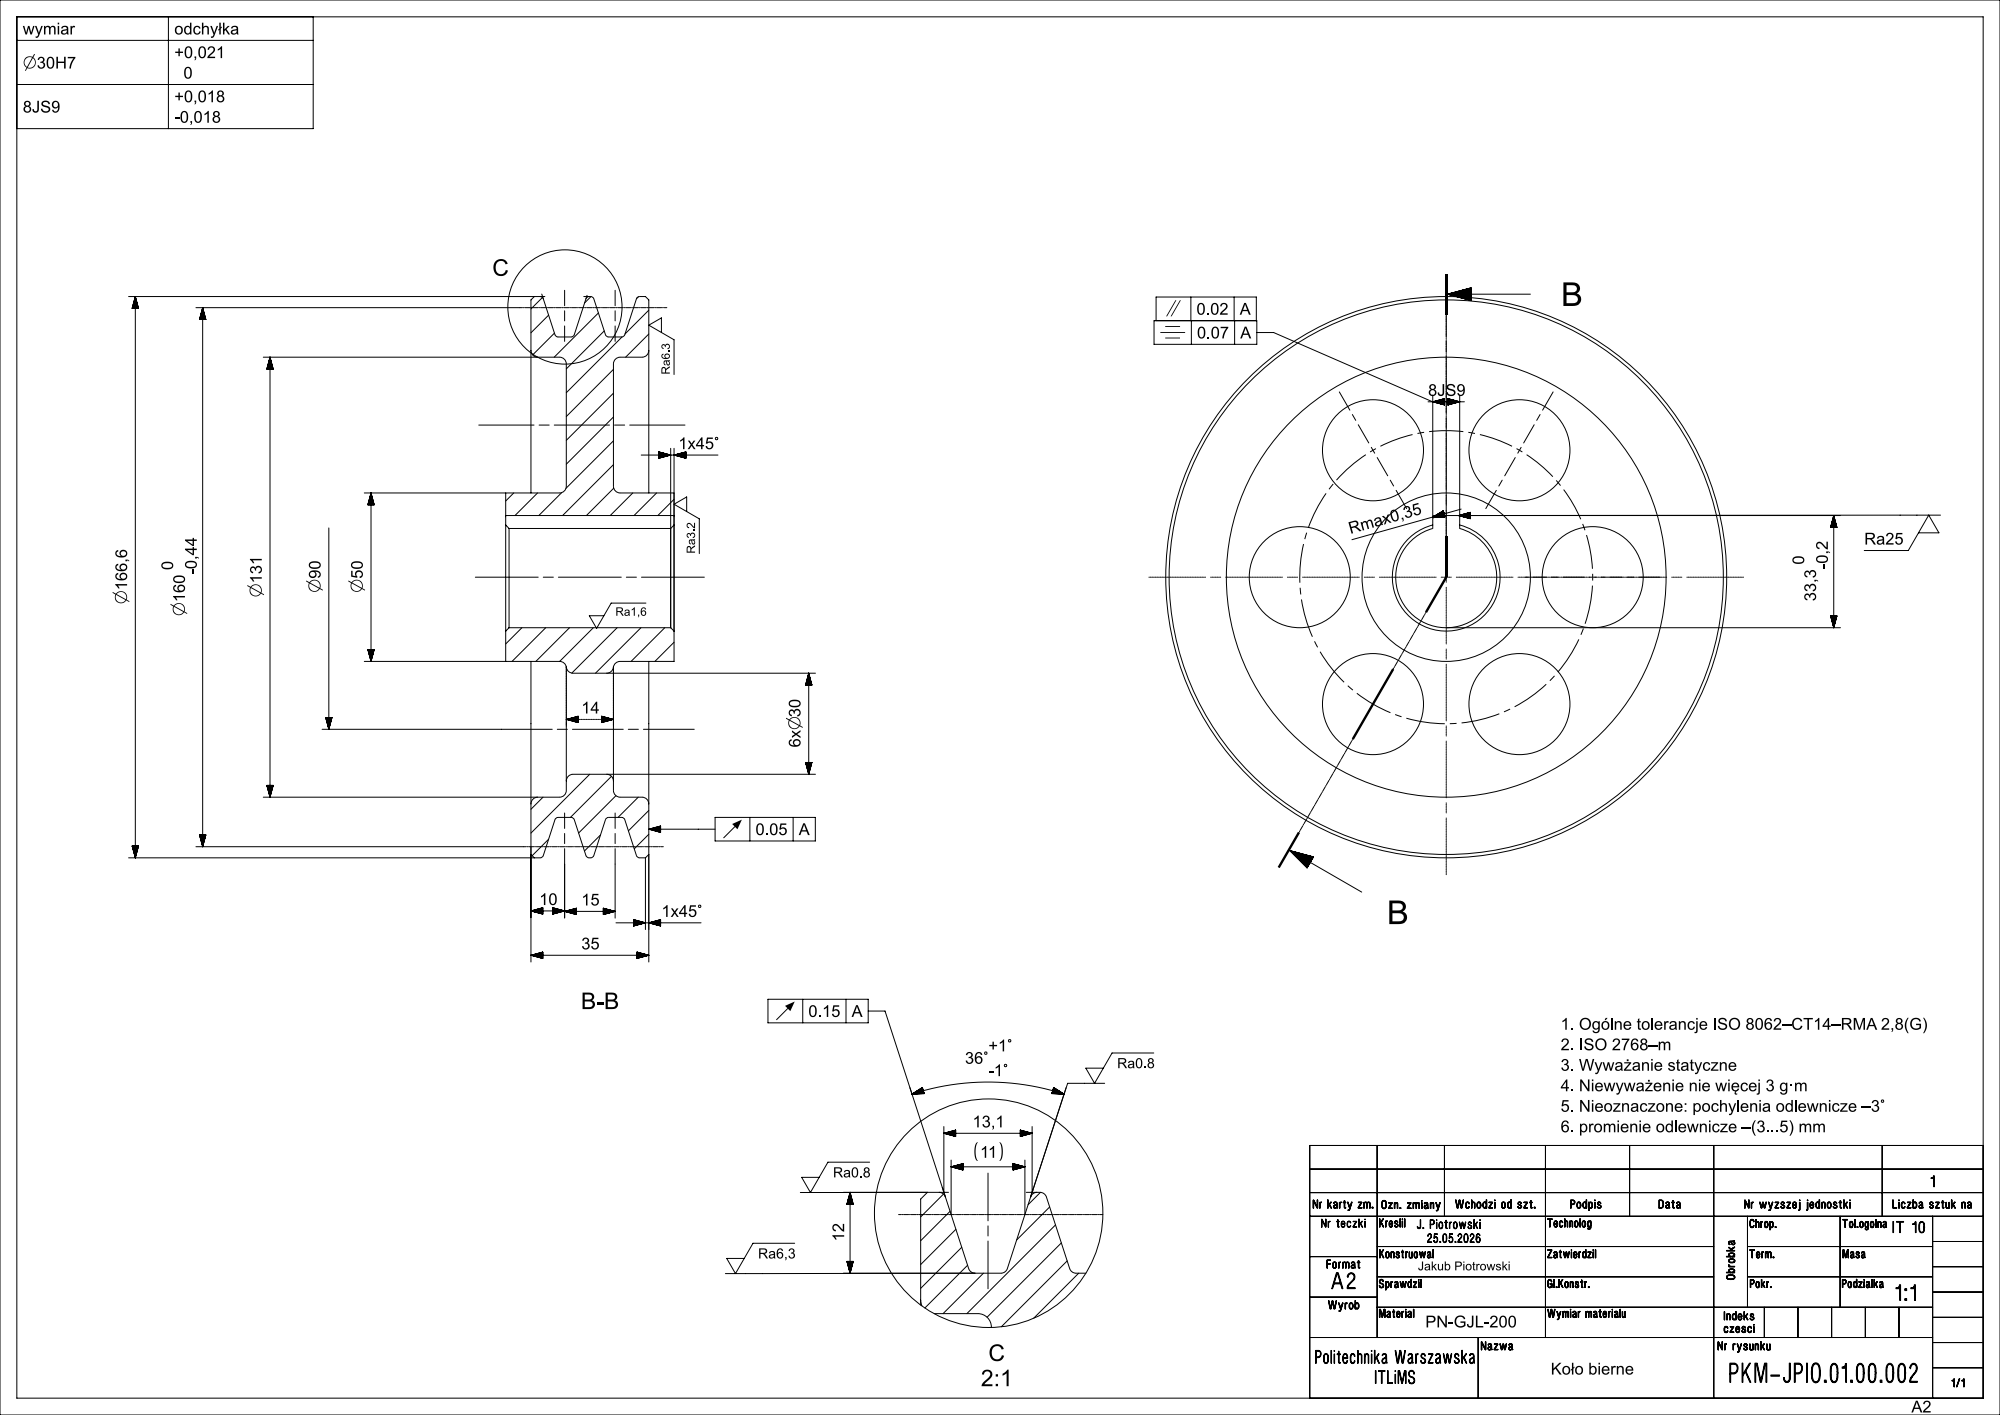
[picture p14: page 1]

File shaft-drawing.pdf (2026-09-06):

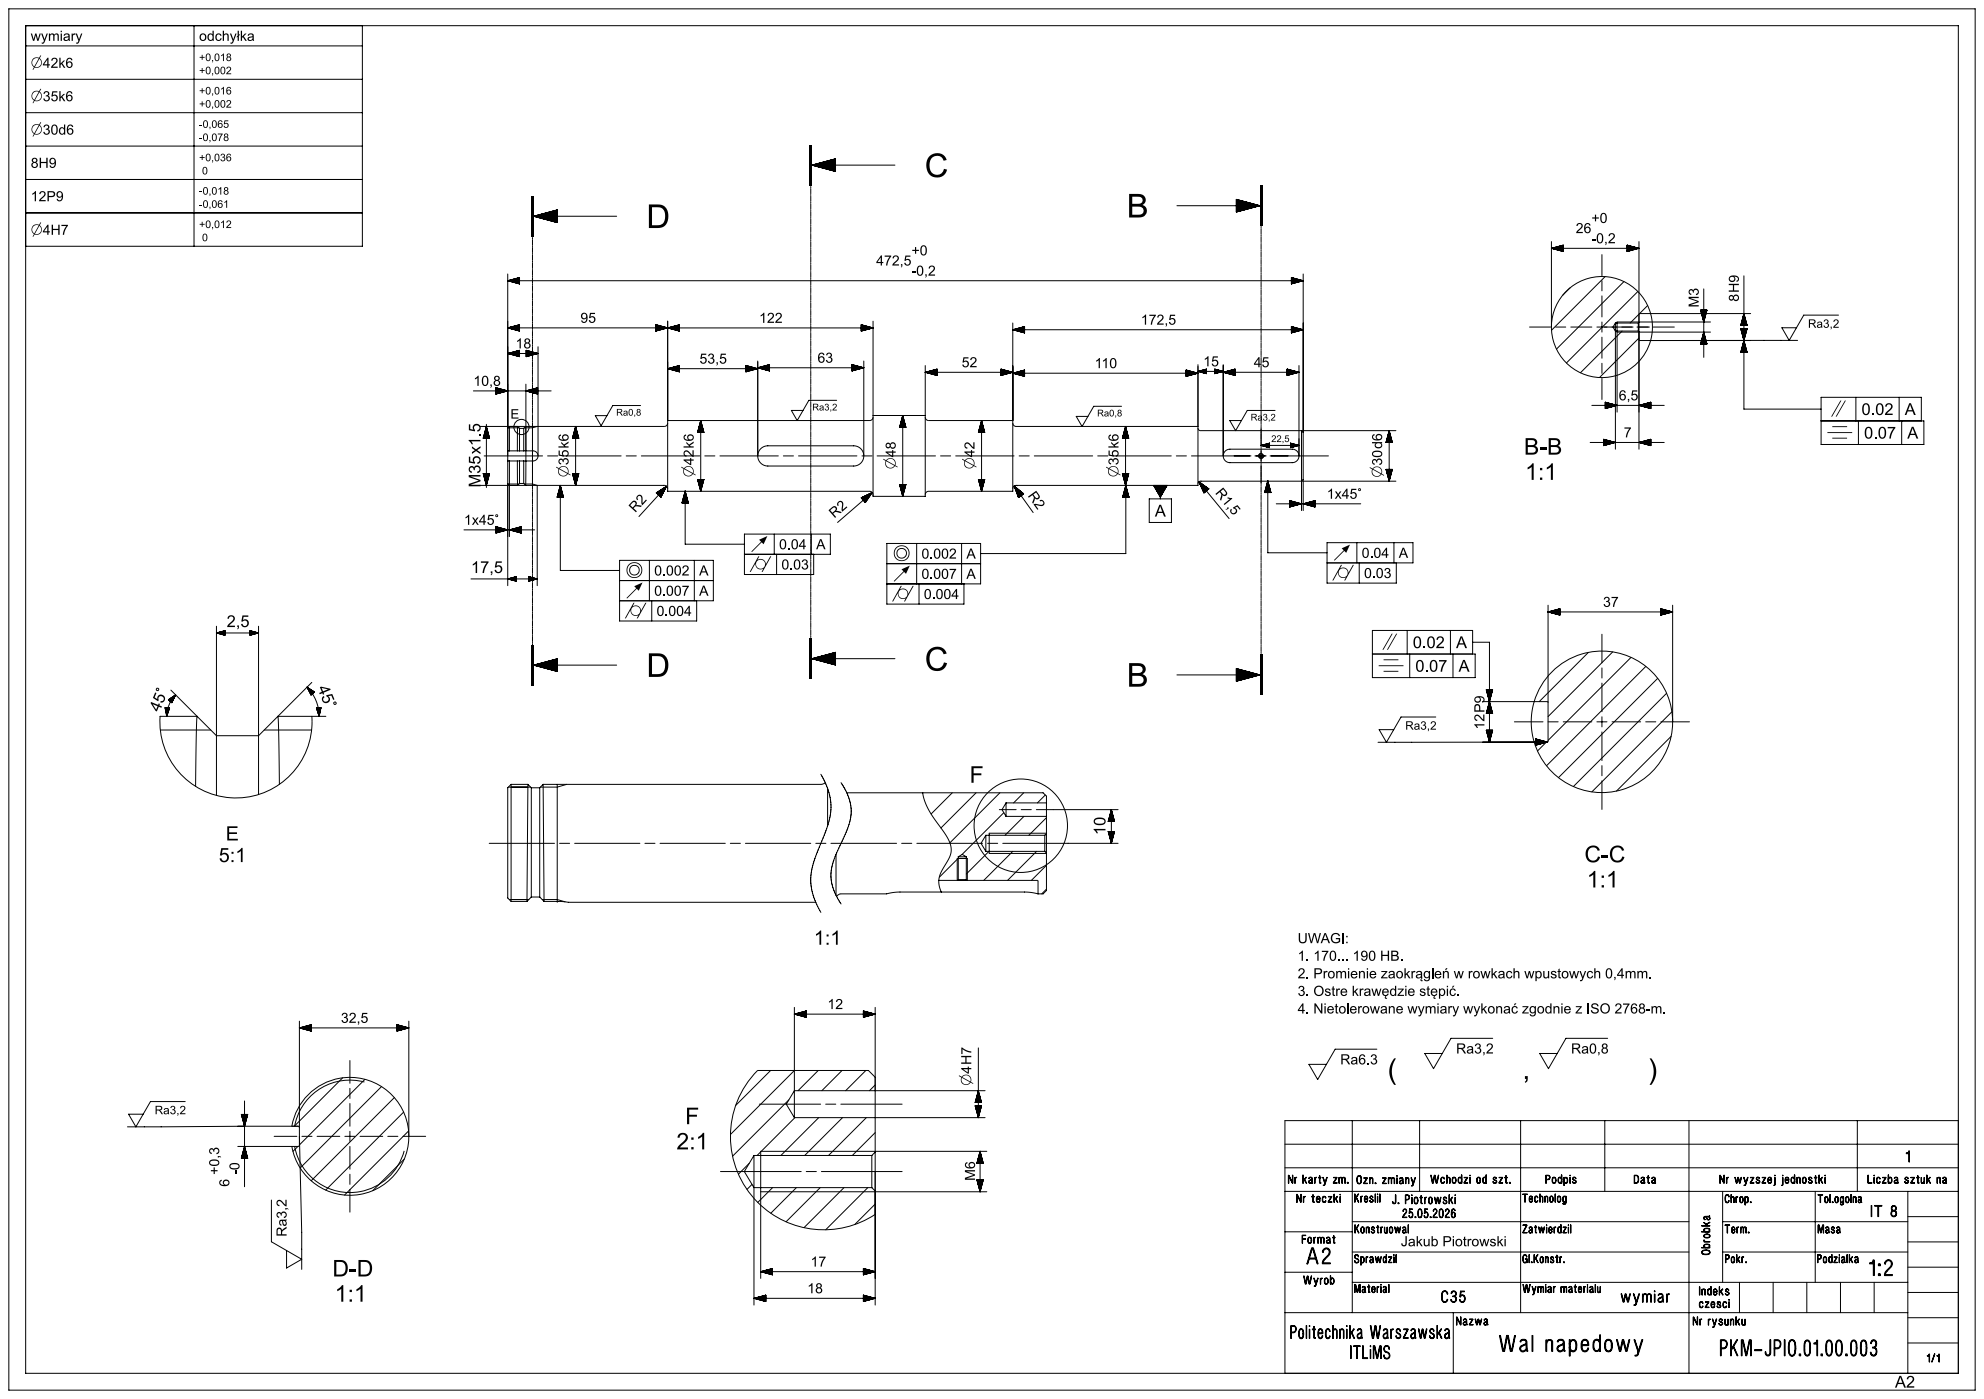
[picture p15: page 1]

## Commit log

2026-09-06 Initial commit: napęd wentylatora (PKM) - dokumentacja, rysunki i model STL
    [assembly1 — kopia.stl]
2026-09-06 Ujednolicenie nazw plikow do konwencji angielskiej (CV)
    [fan-assembly.stl]
